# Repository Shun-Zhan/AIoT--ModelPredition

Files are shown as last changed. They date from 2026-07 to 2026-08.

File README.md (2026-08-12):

# ESP32-S3 智能灌溉

这是一个离线优先的智能灌溉系统。**ESP32-S3 是唯一的生产业务节点**：采集、五分钟历史、N-BEATS/SoilLSTM 推理、灌溉安全规则、水阀执行和可选云端大模型都在设备上完成。电脑或手机网页只是显示数据和转发用户操作；它们断开、关机或无互联网时，ESP32 的采集、预测和本地自动灌溉仍可继续运行。

官方赛题：[2026 乐鑫科技赛道 PDF](https://iot.sjtu.edu.cn/ueditor/net/upload/file/20260329/6391039317778793056390288.pdf)。

## 生产架构

```mermaid
flowchart LR
  S[传感器] --> E[ESP32-S3]
  E --> H[五分钟 V2 历史和 NTP 时间]
  H --> M[N-BEATS + SoilLSTM]
  M --> R[本地灌溉安全规则]
  R --> V[GPIO11 继电器和水阀]
  E <-->|Wi-Fi TCP 或 USB| D[电脑 Dashboard]
  D -->|UI 命令| E
  E <-->|可选 HTTPS| C[火山引擎云端大模型]
```

- ESP32 本地规则始终优先于云端建议。云端只能解释、问答和给出建议，不能绕过设备安全门或直接操作 GPIO11。
- 自动灌溉每次重启均关闭，需在 Dashboard 中人工启用；即使已启用，设备仍会校验 NTP 时间、完整传感器、288 点连续窗口、冷却时间、单次最长 60 秒和每日最长 600 秒。
- PC 端不运行生产预测、不做生产决策、不调用云端，也不保存或索取云端 API Key。训练和模型导出仍是开发工具，和日常 Dashboard 启动无关。

## 一键启动 Dashboard

仅需 Python 3.10+。首次启动会建立 `.venv` 并安装网页/串口接收依赖；**不检查云端 Key，也不读取 `artifacts/` 模型文件**。

### Windows

Wi-Fi 接收（推荐）：

```powershell
cd C:\Users\你的用户名\Desktop\AIoT--ModelPredition
.\start_dashboard.cmd -Wifi -Lan
```

USB 接收：

```powershell
.\start_dashboard.cmd -EspSerialPort COM3 -Lan
```

`-Lan` 让同一局域网中的手机访问 `http://电脑IPv4:8000/dashboard`。Windows 防火墙仅允许“专用网络”。停止后台进程：

```powershell
.\stop_dashboard.cmd
```

### macOS / Linux

Wi-Fi 接收（自动发现 ESP32）：

```bash
cd /你的路径/AIoT--ModelPredition
./start_dashboard.sh --wifi --lan
```

USB 接收：

```bash
./start_dashboard.sh --serial-port /dev/cu.wchusbserial10 --lan
```

若热点屏蔽 UDP 广播和 mDNS，可将串口打印的设备 IP 显式传入：

```bash
./start_dashboard.sh --wifi --esp-wifi-host 172.20.10.2 --lan
```

## Dashboard 的职责

Dashboard 从设备接收 `@TELEMETRY`、`@FORECAST`、`@IRRIGATION_STATE`、`@CLOUD_RESULT` 和 `@UI_ACK`，将最近状态缓存到 SQLite 后展示。网页按钮只写入待转发的 `@UI_COMMAND`；ESP32 收到后必须再次审核，再返回 ACK。

```text
网页按钮 -> 电脑转发 @UI_COMMAND -> ESP32 安全审核 -> @UI_ACK / @IRRIGATION_STATE -> Dashboard
```

因此“打开水阀”按钮只是请求，不能保证已经打开。以设备返回的 `@UI_ACK` 和 `@IRRIGATION_STATE` 中的阀门状态为准；`STOP_WATERING` 是任何状态下都允许的保守操作。

电脑断开后重新连接，Dashboard 只请求设备当前状态与后续遥测，不会把 PC 上陈旧的预测或决策下发给设备。

## ESP32 离线采集与预测

设备上电默认是 `OFFLINE_LOGGING`，每 **5 分钟**保存一个完整样本。任一必需传感器失败时，该 slot 不写入；设备每 15 秒重试，跨过 slot 仍失败则形成缺口，连续预测窗口从下一条完整样本重新累计。

- 连续 288 个五分钟样本为 24 小时窗口。满足后 ESP32 运行 float32 N-BEATS 和两层 SoilLSTM，输出下一小时 ET₀ 与 12 个五分钟土壤湿度预测点。
- 本方案不使用硬件 RTC。设备每次上电必须先成功连接互联网并完成 NTP 校时；Wi-Fi 连通后约 5 秒开始校时重试。当前运行周期内可继续离线采集、预测和自动灌溉，但断网重启后会回到 `clock_unset`，直到下一次 NTP 校时。
- `warming_up`、`clock_unset` 或模型错误时，可显示轻量 `edge_prediction` 风险提示；它不能直接开阀。
- 记录采用 V2（二进制版本、长度、连续序号、UTC epoch、slot、传感器有效标志和 CRC）。启动会恢复最新连续 288 条 V2 数据；不会要求再次等待 24 小时。

### 升级旧日志

V1 离线记录与 V2 不兼容。升级前先通过 USB 导出旧记录：

```bash
dual-forecast offline-log --action export
```

确认 CSV 已保存并检查后，再使用交互式二次确认或显式 `erase` 清除旧 V1 文件。固件不会静默删除或伪造迁移旧记录。

### 从导出 CSV 回灌预测历史

同一份由 `offline-log --action export` 导出的 CSV 可以通过 USB 回灌到 ESP32，作为模型的初始历史；无需切换到另一份演示固件。回灌只替换 ESP32 的 **V2 预测历史窗口**，不会删除普通离线导出日志、Wi-Fi 配置或云端配置；开始时会强制关阀并关闭自动灌溉。

先停止占用 USB 串口的 Dashboard/Arduino 串口监视器，再执行：

```bash
./stop_dashboard.sh
.venv/bin/python -m dual_forecast.cli offline-log \
  --serial-port /dev/cu.wchusbserial10 \
  --action import \
  --input "/完整路径/esp32-offline-log.csv"
```

Windows PowerShell：

```powershell
.\stop_dashboard.cmd
.\.venv\Scripts\python.exe -m dual_forecast.cli offline-log `
  --serial-port COM3 `
  --action import `
  --input "C:\完整路径\esp32-offline-log.csv"
```

电脑会校验原始导出列、传感器有效标志和五分钟连续性，并选取 CSV 中最长的一段连续完整记录，最多 288 条。旧 CSV 没有 UTC 时间列，ESP32 会按导入完成时刻向前连续排列这些历史点，再继续追加之后的真实五分钟采样。

- 导入 288 条：ESP32 立即排队运行模型，Dashboard 收到 `@FORECAST` 后自动画出一小时趋势图。
- 导入少于 288 条：Dashboard 显示 `N/288`，设备继续采集到 288 条后自动推理。例如导入 94 条，还需 194 条完整真实样本。
- CSV 中跨重启、缺采样或传感器失败的段不会拼接，避免把不连续时间序列误用于模型。

## 云端大模型

云端是可选增强，设备在有互联网时通过 HTTPS 直接访问火山引擎 OpenAI 兼容网关。API Key、是否启用、模型名和农田档案均由 ESP32 配网页面保存到设备 NVS：

- Key 不回显、不写入串口日志、遥测、SQLite 或 Git。
- 配网页面只显示“已配置”；提交空 Key 时保留现有 Key，清除需要显式操作。
- 网络、TLS、JSON 或网关失败只产生设备状态，**不影响**本地采集、预测和安全控制。
- 曾经暴露在终端、聊天记录或截图中的 Key 必须在正式部署前作废并重新生成。

电脑侧 `.env` 不再是云端配置位置。电脑没有网络时仍能显示设备数据；ESP32 所在局域网若没有互联网，则设备照常离线运行，云端请求显示为不可用即可。

## 硬件接线

| 功能 | ESP32-S3 引脚 | 接线/说明 |
| --- | --- | --- |
| 风速（当前使用） | GPIO6 ADC | OUT；若模块输出 0–5 V，必须分压到 0–3.3 V |
| 风速预留 | GPIO9 | 当前不接、不采样 |
| AHT20 | GPIO5 / GPIO8 | SDA / SCL，3.3 V，I²C 地址 0x38 |
| HW-611 BMP280 | GPIO3 / GPIO4 | SDA / SCL，3.3 V；CSB→3.3 V；SDO→GND 通常为 0x76 |
| ZH-SOIL7 土壤 | GPIO18 / GPIO17 | 设备 TTL UART 的 RX / TX，4800 8N1，Modbus-RTU 地址 0x03 |
| SN-300AL 太阳辐射 | GPIO16 / GPIO15 | 经自动收发 RS485 转换器的 RO / DI；4800 8N1，地址 0x01/0x02 |
| 水阀继电器 | GPIO11 | IN，3.3 V 单路继电器，高电平有效；上电默认 LOW |
| Feather I²C 电源控制 | GPIO7 | 不外接，禁止复用 |

土壤传感器这一版是 **TTL UART 电气层**，不是 RS485 电气层：模块的 TX 接 ESP32 GPIO18（RX），模块的 RX 接 ESP32 GPIO17（TX），并与 ESP32 共地。它传输的帧格式仍可以是 Modbus-RTU；“Modbus-RTU”是通信协议，不能据此判断必须使用 RS485。

太阳辐射总线才使用 RS485：两个探头 A 对 A、B 对 B 并联，接到独立的自动收发 RS485 转换器；转换器 RO→GPIO16，DI→GPIO15。太阳 1（0x01）是反射短波，太阳 2（0x02）是入射短波，净短波为 `max(入射 - 反射, 0)`。

本方案没有硬件 RTC。设备仅在 NTP 校时成功后将 ESP32 系统时钟视为可信时间；当前运行周期内即使暂时断网仍可继续采集、预测和自动灌溉，但断网重启后必须再次联网校时。

水阀的低压侧：继电器 DC+/VCC 接模块要求的 3.3 V，DC-/GND 与 ESP32 共地，IN 接 GPIO11。24 V 常闭水阀的触点侧：24 V 正极→COM，NO→水阀正极，水阀负极→24 V 负极。确认继电器触点的直流额定值高于负载；24 V 不能进入 ESP32 GPIO 或继电器 IN。

## ESP32 配网

无已保存网络、首次烧录或收到 `@WIFI_RESET` 时，ESP32 建立 `AIOT-SETUP-xxxxxx` 热点，密码为 `12345678`，在 `http://192.168.4.1/` 配置 2.4 GHz WPA2 网络。网络凭据和云端配置仅保存在 ESP32 NVS。普通手机热点、Windows 移动热点和家用路由器可用；5 GHz、网页认证/验证码和多数 802.1X 校园网需要专门适配。

## 开发：训练与模型导出

训练只在开发电脑进行；生产 Dashboard 启动不需要 `artifacts/`。模型更新后执行导出，再重新烧录 ESP32：

```bash
.venv/bin/python scripts/export_esp32_models.py
.venv/bin/python scripts/export_esp32_models.py --check
```

导出生成 `firmware/esp32_s3_all_sensors/generated/model_data.h`，其中包含 float32 权重、标准化器、模型版本和 SHA-256。不要手改该文件。

### Arduino 依赖与编译

Arduino IDE / `arduino-cli` 需安装 **ArduinoJson 7.4.2**。板型选择 `Adafruit Feather ESP32-S3 No PSRAM`，分区选择 `Default (3MB APP/1.5MB SPIFFS)`：

```bash
arduino-cli compile \
  --fqbn 'esp32:esp32:adafruit_feather_esp32s3_nopsram:PartitionScheme=default_8MB,CDCOnBoot=default,UploadMode=default' \
  --build-path /tmp/aiot-esp32-build \
  firmware/esp32_s3_all_sensors
```

详细固件协议与离线日志操作见 [firmware/esp32_s3_all_sensors/README.md](firmware/esp32_s3_all_sensors/README.md)。

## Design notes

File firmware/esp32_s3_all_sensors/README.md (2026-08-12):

# ESP32-S3 固件

该目录的固件是生产业务权威：它在 ESP32-S3 本机完成传感器采集、NTP 校时、离线 V2 历史、float32 N-BEATS/SoilLSTM 推理、灌溉安全审核、水阀控制，以及可选火山引擎云端大模型调用。电脑端仅接收和显示设备消息，并转发网页请求；电脑不参与生产预测、决策或云端调用。

## IDE 与依赖

使用 Arduino IDE 打开 `esp32_s3_all_sensors.ino`。板型选择 **Adafruit Feather ESP32-S3 No PSRAM**，Tools → Partition Scheme 选择 **Default (3MB APP/1.5MB SPIFFS)**。不要选 TinyUF2 FATFS 分区，否则 LittleFS 无法挂载。

通过 CH340 `/dev/cu.wchusbserial*` 或 Windows `COM*` 烧录时，设置 USB CDC On Boot → Disabled、Upload Mode → UART0 / Hardware CDC。

除 ESP32 Arduino Core 外，还需安装 **ArduinoJson 7.4.2**。模型权重由仓库根目录的 `scripts/export_esp32_models.py` 生成 `generated/model_data.h`，更新模型后必须重新烧录；不要手动修改生成文件。

```bash
.venv/bin/python scripts/export_esp32_models.py --check
arduino-cli compile \
  --fqbn 'esp32:esp32:adafruit_feather_esp32s3_nopsram:PartitionScheme=default_8MB,CDCOnBoot=default,UploadMode=default' \
  --build-path /tmp/aiot-esp32-build \
  firmware/esp32_s3_all_sensors
```

## 引脚与接线

| 功能 | ESP32-S3 | 外设侧 | 说明 |
| --- | --- | --- | --- |
| 风速（启用） | GPIO6 | OUT | ADC；0–5 V 信号先分压至 0–3.3 V |
| 风速预留 | GPIO9 | 不接 | 当前不采样 |
| AHT20 | GPIO5 / GPIO8 | SDA / SCL | 3.3 V，地址 0x38 |
| BMP280 / HW-611 | GPIO3 / GPIO4 | SDA / SCL | 3.3 V；CSB→3.3 V；SDO→GND 常为 0x76 |
| ZH-SOIL7 土壤 | GPIO18 / GPIO17 | TX / RX | TTL UART，4800 8N1，Modbus-RTU 地址 0x03 |
| SN-300AL 太阳辐射 | GPIO16 / GPIO15 | RS485 转换器 RO / DI | 4800 8N1，地址 0x01/0x02 |
| 水阀继电器 | GPIO11 | IN | 3.3 V、高电平有效；上电先置 LOW |
| Feather I²C 电源控制 | GPIO7 | 不外接 | 固件自动拉高，禁止复用 |

所有模块必须共地。本方案没有硬件 RTC：设备每次启动后先连接有互联网的 Wi-Fi，通过 NTP 校准 ESP32 系统时钟；Wi-Fi 连通后约 5 秒开始校时重试。校时成功前预测状态为 `clock_unset`，自动灌溉不会开启。校时成功后，在本次运行周期内即使暂时断网，设备仍可继续采集、预测和自动灌溉；断网重启则需再次 NTP 校时。

**土壤不是 RS485 电气层。** 该版本的 ZH-SOIL7 使用 TTL UART：传感器 TX→GPIO18（ESP32 RX），传感器 RX→GPIO17（ESP32 TX），共地。它的帧协议仍为 Modbus-RTU；协议不等于电气层，因此不要额外串接 RS485 转换器。

太阳辐射才需要 RS485 转换器：两个太阳探头 A 对 A、B 对 B 并联在独立太阳总线上，转换器 RO→GPIO16，DI→GPIO15。地址 0x01 是反射短波，0x02 是入射短波；净短波为 `max(入射 - 反射, 0)`。

继电器控制侧：DC+/VCC→模块要求的 3.3 V，DC-/GND→ESP32 GND，IN→GPIO11。24 V 常闭水阀的触点侧：24 V 正极→COM，NO→水阀正极，水阀负极→24 V 负极。24 V 不得接入 GPIO 或 IN；触点额定直流电压/电流应高于水阀负载。

## 离线记录、预测与安全

上电默认是 `OFFLINE_LOGGING`，每 **5 分钟**尝试写入一个完整样本。任一必需传感器失败时，该样本不会写入；设备每 15 秒重试，跨越本 slot 后记录缺口，新的连续窗口从下一条完整样本开始。

- V2 记录包含版本、记录长度、序号、UTC epoch、五分钟 slot、有效传感器标志和 CRC。
- 从 LittleFS 的轮换文件恢复最新连续 288 条 V2 记录。288 条完整的五分钟样本等于 24 小时，可立即推理。
- V1 与 V2 不兼容。升级前先用 `dual-forecast offline-log --action export` 导出 CSV；确认文件可用后，才通过明确 `erase` 操作清除旧记录。固件不静默清空 V1。
- 导出 CSV 可通过 `dual-forecast offline-log --action import --input <csv>` 经 USB 回灌到 V2 预测历史。导入时设备强制关阀并关闭自动模式；电脑校验 CSV 的完整记录和五分钟连续性，选择最长连续段，最多 288 条。导入 288 条立即推理，少于 288 条则继续追加真实采样直到窗口满。
- 本方案不使用硬件 RTC。设备在 NTP 校时成功后可将系统时钟作为当前运行周期的可信时间源；断网重启后回到 `clock_unset`，直到再次 NTP 校时。时间无效、窗口未满、缺失数据或模型错误时，仅允许 `edge_prediction` 风险提示，禁止自动开阀。
- 自动模式只保存在 RAM，**每次重启默认关闭**。即使人工打开自动模式，也要满足完整传感器、预测就绪、冷却、单次 60 秒和每日 600 秒限额。
- 本地自动开阀不依赖电脑心跳；PC 发起的调试/人工开阀仍受传输心跳保护。任何状态都接受 STOP 并关阀。

## Wi-Fi、云端与配网

首次烧录、没有已保存网络或收到 `@WIFI_RESET` 时，设备会创建 `AIOT-SETUP-xxxxxx` 配置热点，密码 `12345678`，页面为 `http://192.168.4.1/`。支持 2.4 GHz WPA2 网络、手机热点和 Windows 移动热点；5 GHz、网页认证和 802.1X 校园网需额外适配。

配网页面保存 Wi-Fi 凭据，以及云端开关、模型名、农田档案和 API Key。云端 Key 只保存在 ESP32 NVS：页面只显示是否已配置，绝不回显、写日志、出现在遥测或提交到 Git。空 Key 更新保留旧 Key；清除是显式操作。

设备通过 HTTPS 直接调用火山引擎网关，并验证根证书；禁止使用 `setInsecure()`。云端网络/TLS/JSON/服务失败时只返回离线状态，采集、预测和本地安全闭环继续运行。正式部署前应作废历史聊天、终端或截图中泄露过的 Key。

## 与 Dashboard 的协议

设备上行：

```text
@TELEMETRY { ... }
@FORECAST { "schemaVersion":"2.0", ... }
@IRRIGATION_STATE { "schemaVersion":"2.0", ... }
@CLOUD_RESULT { "schemaVersion":"2.0", ... }
@UI_ACK { "schemaVersion":"2.0", ... }
```

电脑/网页下行：

```text
@UI_COMMAND { "action":"SET_AUTO_MODE" | "CONFIRM_WATERING" | "CANCEL" | "STOP_WATERING" | "CLOUD_ANALYZE" | "CLOUD_CHAT", ... }
```

设备对所有开阀请求重新执行完整安全审核。Dashboard 的按钮表示“已请求”，不是“已执行”；以 `@UI_ACK` 和 `@IRRIGATION_STATE` 中的设备状态为准。

Wi-Fi 模式下设备以 UDP 3334 广播、TCP 3333 提供遥测端点；电脑可自动发现。USB 波特率为 115200，Arduino 串口监视器不能与电脑接收器同时占用该端口。

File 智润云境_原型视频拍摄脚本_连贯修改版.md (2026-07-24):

# 《智润云境》作品原型视频拍摄脚本（连贯修改版）

## 一、成片定位

- 建议时长：6 分 30 秒左右（可接受范围 6–7 分钟）
- 叙事主线：校园灌溉痛点 → 系统组成 → 实时感知 → 本地预测 → 云端分析 → 灌溉执行 → 创新总结
- 核心记忆点：系统不是“湿度低就浇水”，而是综合环境数据预测需水趋势，再给出有依据的灌溉建议
- 推荐形式：1 名主讲人出镜，另 1 名队员操作；以实物演示和录屏为主，架构图只做辅助
- 开场原则：前 20 秒出现作品实物或阀门出水画面，前 1 分钟说清作品解决什么问题

## 二、拍摄前准备

### 必拍实物

1. ESP32-S3 主控板近景，芯片或模组型号清晰可见。
2. AHT20、BMP280/BME280、RS485 土壤温湿度、双路太阳辐射和当前启用的单路风速传感器。
3. 电脑端边缘网关、GPIO11 继电器、24 V 常闭水阀、管路和盆栽或模拟绿地。
4. 电脑上的实时 Dashboard、预测模型状态、云端分析结果和执行日志。
5. 火山引擎大模型的真实问答或分析摘要。

### 建议提前准备的演示状态

- 实时数据可以稳定刷新，传感器均正常在线。
- 准备一盆偏干土壤，或加载一段标明“历史实测回放”的真实干燥数据。
- 电磁阀或水泵能够安全动作，出水效果清楚。
- 提前积累足够的连续数据，确保预测模型能够返回结果。
- 提前测试大模型问答，避免现场因网络或接口波动影响拍摄。

> 如果现场无法稳定复现某个状态，可以使用提前录制的真实测试片段，并在画面上标注“历史实测回放”。不要把模拟数据包装成现场实测数据。

## 三、详细分镜与口播

| 时间 | 画面与镜头 | 口播参考 | 屏幕字幕/后期提示 |
|---|---|---|---|
| 00:00–00:12 | 干燥土壤特写 → Dashboard 出现缺水风险 → 阀门开启出水 → 作品全景。 | “如果校园绿化不再只按固定时间浇水，而是能提前判断植物接下来是否缺水，会发生什么？” | 大字标题：`智润云境`；副标题：`边缘 AIoT 智慧灌溉决策系统` |
| 00:12–00:35 | 主讲人站在原型旁，中景；穿插校园草坪或盆栽画面。 | “大家好，我们的作品是‘智润云境’。针对校园绿化依赖人工经验、定时灌溉容易造成用水不合理的问题，我们设计了一套集环境感知、本地预测、智能分析和灌溉控制于一体的系统。” | 关键词：`多源感知`、`趋势预测`、`按需灌溉` |
| 00:35–00:58 | 左侧展示传统阈值判断，右侧展示系统流程简图。 | “普通灌溉系统往往只看土壤湿度：低于阈值就浇水。但植物的需水状态还会受到气温、空气湿度、太阳辐射和风速影响。我们的系统把这些数据放在一起分析，预测未来一小时的蒸散和土壤湿度变化。” | 对比字幕：`单一湿度阈值` → `多源数据 + 趋势预测` |
| 00:58–01:22 | 推近 ESP32-S3，依次扫过各传感器，并标注名称。 | “系统以乐鑫 ESP32-S3 为核心主控，采集空气温湿度、大气压力、土壤温湿度、风速和两路太阳辐射。Solar 2 测量入射短波，Solar 1 测量反射短波，两者相减得到净短波辐射，为 ET₀，也就是参考作物蒸散量的计算和预测提供输入。” | `指定主控：ESP32-S3`；`Rs↓−Rs↑＝净短波辐射` |
| 01:22–01:50 | 展示 Wi-Fi TCP 数据流、USB 连接和电脑端 Dashboard，录到实时数据刷新。 | “ESP32-S3 通过同一 2.4 GHz 局域网，把采集数据经 TCP 发送到电脑，USB 作为备用连接。电脑上的 FastAPI 负责接收数据并把功能提供给网页，SQLite 则像一本保存在本机的电子台账，记录传感器数据、预测结果和操作日志。神经网络也在这台电脑上运行，ESP32 主要负责采集和执行。” | 简图：`传感器 → ESP32-S3 → Wi-Fi TCP / USB → 电脑端`；角标：`FastAPI：本地服务`、`SQLite：本地数据存储` |
| 01:50–02:05 | 作品全景俯拍，再切到土壤探头插入偏干土壤。 | “下面以一组偏干土壤数据为例，看看系统怎样从实时感知走到灌溉建议。” | 章节条：`原型演示：从感知到执行` |
| 02:05–02:32 | Dashboard 录屏，传感器卡片持续刷新；画中画保留实物。 | “ESP32-S3 持续采集环境数据，页面同步显示空气、土壤、风速和辐射信息。当前土壤湿度正在下降，同时光照较强，系统会把这些数据整理成连续的时间序列，交给电脑端模型分析。” | 高亮真实读数；角标：`① 多源数据实时感知` |
| 02:32–03:02 | 展示 Dashboard 的未来一小时双曲线，先带到模型状态和样本数，再依次放大 ET₀ 与土壤湿度预测。 | “电脑端以连续二百八十八个五分钟数据点，也就是约二十四小时的数据为输入。N-BEATS 预测未来一小时的 ET₀，LSTM 预测未来十二个五分钟时段的土壤湿度。两条曲线分别使用独立纵轴，可以直观看到蒸散需求和土壤湿度的变化趋势。快速测试模式只用来确认数据链路和模型流程能否跑通，不能作为精度证明。” | `288 个点 ≈ 24 小时`；`预测未来 12 步 ≈ 1 小时`；`快速测试模式只验证链路` |
| 03:02–03:32 | 点击“请求一次分析”，展示火山引擎真实调用结果和结构化建议。 | “有了实时数据和本地预测后，系统可以请求云端大模型进行综合分析。上传的内容包括当前环境、近期趋势、预测结果和设备状态。大模型返回分析依据和结构化建议，帮助运维人员快速理解这片区域当前为什么可能需要灌溉。” | 角标：`② 本地预测 + 云端分析`；高亮数据时间范围和建议内容 |
| 03:32–04:00 | 现场文字或语音提问：“最近是否存在高蒸散风险？”展示回答和依据。 | “运维人员也可以直接提问，比如‘最近是否存在高蒸散风险’。系统会结合已经采集到的数据回答，并标出判断依据。语音输入和朗读由浏览器提供，不支持时仍可正常使用文字问答。” | 角标：`自然语言问答`；显示：`回答依据来自系统数据` |
| 04:00–04:32 | 操作者在 Dashboard 确认灌溉；切到 GPIO11 继电器、水阀出水和页面状态更新，保留 2 秒水流声。 | “当系统给出灌溉建议后，由操作人员在页面确认。电脑把控制指令发送给 ESP32-S3，主控驱动 GPIO11 继电器打开水阀。设备返回执行结果后，页面同步更新状态，完成从感知、预测到实际灌溉的闭环。” | 流程逐项点亮：`感知 → 预测 → 建议 → 确认 → 执行` |
| 04:32–04:52 | 展示灌溉后的土壤湿度变化和操作日志。 | “灌溉过程中，系统继续采集土壤数据，并记录建议时间、执行时长和设备反馈。这些历史记录可以用于复盘，也能为后续模型优化提供数据。” | 角标：`③ 过程可记录、结果可追溯` |
| 04:52–05:28 | 简洁架构图全屏，随后快速切换净短波、预测结果、云端问答和手机 Dashboard。 | “整套系统分为三层：ESP32-S3 完成现场感知和设备执行；电脑端保存数据、运行预测模型并提供可视化页面；云端大模型负责结合上下文生成分析建议。三部分通过清晰的数据接口配合，既能展示完整的 AIoT 链路，也方便后续扩展。” | 三层架构：`设备端`、`电脑端边缘网关`、`云端大模型` |
| 05:28–06:02 | 依次展示双太阳辐射、模型预测、手机访问页面和实物运行画面。 | “项目有三个主要特点。第一，分别测量入射和反射太阳辐射，用净短波数据支撑 ET₀ 分析；第二，在电脑端同时使用 N-BEATS 和 LSTM，分别预测蒸散与土壤湿度趋势；第三，电脑和手机都能在局域网内查看实时状态，方便现场巡检。” | 大字：`净短波感知`、`双模型预测`、`局域网巡检` |
| 06:02–06:25 | 展示主控、传感器、RS485 转换器、继电器、24 V 常闭水阀和电脑页面。 | “从传感器采集、局域网传输，到本地预测、云端分析和水阀执行，我们已经完成了可运行的原型闭环。后续还会继续积累真实土壤数据，对模型进行校准和评估。” | 字幕：`真实原型闭环`；`持续积累实测数据` |
| 06:25–06:42 | 团队成员与作品同框，最后切作品 Logo。 | “智润云境，让灌溉从按时执行，走向按需决策。以上是我们的作品介绍，感谢各位评委老师。” | 收尾：作品名、团队名；不要出现 Wi-Fi 密码、API Key 或个人联系方式 |

## 四、可直接使用的 30 秒开场词

“如果校园绿化不再只按固定时间浇水，而是能结合土壤状态和蒸散趋势，提前判断植物接下来是否缺水，会发生什么？大家好，我们的作品是‘智润云境’，一套基于 ESP32-S3、电脑端预测模型和云端大模型的智慧灌溉系统。它采集空气、土壤、风速和太阳辐射数据，通过 N-BEATS 和 LSTM 预测未来趋势，再把分析结果转化为清楚、可追溯的灌溉建议。接下来，我们用真实原型演示这条完整链路。”

## 五、关于预测画面的拍摄说明

当前 Dashboard 已经能够显示：

- 模型当前状态；
- 已积累的连续样本数；
- 未来 12 个五分钟时段的 ET₀ 预测曲线；
- 未来 12 个五分钟时段的土壤湿度预测曲线；
- 未来一小时累计 ET₀，以及土壤湿度起止值摘要。

两张图使用独立纵轴，拍摄时可以先展示完整卡片，再分别放大曲线。模型未积累满 288 个连续数据点时，页面会显示预热提示，不会生成虚假的占位曲线。

## 六、拍摄与剪辑建议

### 镜头

- 统一使用横屏 16:9，建议拍摄和导出分辨率为 1920×1080。
- 人物口播使用固定机位，实物近景缓慢推拉，避免全程手持晃动。
- 页面内容优先录屏，再与实物画面做画中画组合。
- 每个关键实物至少准备全景、中景和接口或型号特写。
- 阀门出水是全片最直观的动作，可从继电器指示灯、阀门和出水口三个角度拍摄。

### 声音

- 在安静环境单独录制口播，手机或领夹麦距离嘴部约 15–20 cm。
- 背景音乐保持较低音量，阀门动作和水流声可以短暂保留。
- 专业名词配字幕即可，不要把整段口播全文堆在画面上。

### 节奏

- 开头 1 分钟每 3–5 秒切换一次镜头，尽快建立问题和作品印象。
- 原型演示段的每个页面停留 5–8 秒，让评委看清真实数据。
- 每个镜头只解释一个重点，复杂公式放在设计文档中。
- 转场以直切和简单淡入淡出为主，不让动画盖过实物。

## 七、赛题要求显性对照

| 赛题必备项 | 口播必须说到 | 对应证据画面 |
|---|---|---|
| 指定乐鑫主控 | “以乐鑫 ESP32-S3 为核心主控” | 模组型号清晰特写 |
| 传感器数据融合 | “综合空气、土壤、风速和太阳辐射数据” | 多传感器实物 + 实时数据卡片 |
| 对接云端大模型 | “通过火山引擎接口请求云端大模型分析” | 真实请求结果或问答界面 |
| 上下行交互 | “上传系统数据，返回分析建议” | 请求内容摘要 + 返回结果 |

可以自然带出的加分点包括净短波感知、N-BEATS/LSTM 双模型预测、自然语言交互、手机巡检和常闭水阀。节水可以作为项目目标，但在没有对照实验前不要展示具体节水百分比。

## 八、常见失分点

1. 不要把视频拍成 PPT 朗读，实物、录屏和真实动作应占主要时长。
2. 前 1 分钟必须出现作品和实际问题，不要先讲过长的项目背景。
3. 不要只说“使用了大模型”，要展示系统向它提供了什么数据、它返回了什么内容。
4. 不要口头宣称“七类传感器”。应以当前实际接线和固件启用情况为准。
5. 不要暴露 Wi-Fi 密码、服务器地址、API Key、学校内网信息或个人联系方式。
6. 不要使用没有记录支撑的精度、节水率或“已经部署”等表述。
7. 拍摄预测曲线时，应同时带到模型状态和样本数，避免把快速测试结果表述成精度验证。

## 九、导出检查

- 容器格式：MP4
- 视频编码：H.264
- 音频编码：AAC
- 分辨率：1920×1080 或更低
- 帧率：25 或 30 fps
- 建议码率：视频 2.5–3.5 Mbps，音频 AAC 128 kbps
- 按 6 分 40 秒、约 3 Mbps 导出，文件通常低于 160 MB
- 导出后完整播放一次，检查黑帧、爆音、字幕出界、数据遮挡和隐私信息

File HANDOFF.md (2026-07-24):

# AIoT 智能灌溉项目交接文档

> 项目目录：`/Users/jiahaoruan/Work/IOT/AIoT--ModelPredition`  
> 最近整理：2026-07-23  
> 交接目标：让下一位开发者能在不依赖聊天记录的前提下，继续完成、验证和提交本项目。

## 1. 当前项目做什么

这是一个 ESP32-S3 智能灌溉系统：ESP32-S3 采集环境数据，通过 Wi-Fi 或 USB 串口发送到电脑；电脑端保存数据、运行本地预测、提供实时 Dashboard、调用可选的火山引擎云端大模型，并在本地安全规则审核后控制 ESP32 GPIO11 上的继电器水阀。

系统采用“离线主干 + 云端增强”设计：局域网断开互联网时，采集、电脑网页、SQLite、本地预测、边缘风险分析、人工确认开关阀仍可使用；云端大模型分析和云端 AI 自动灌溉不可用，且不会因云端失败而开阀。

## 2. 重要目录

| 位置 | 作用 |
| --- | --- |
| `firmware/esp32_s3_all_sensors/esp32_s3_all_sensors.ino` | ESP32-S3 主固件：采集、Wi-Fi 配网/TCP、USB 协议、继电器、设备侧安全保护 |
| `firmware/esp32_s3_all_sensors/README.md` | 最准确的固件接线、烧录、Wi-Fi 和协议说明 |
| `dual_forecast/esp32_receiver.py` | Wi-Fi TCP / USB 串口接收器，接收 `@TELEMETRY`、转发命令并等待 ACK |
| `dual_forecast/service.py` | FastAPI 接口和内嵌 Dashboard 前端 |
| `dual_forecast/irrigation.py` | 云端建议、本地边缘风险、本地安全审核、命令入队 |
| `dual_forecast/cloud.py` | 火山引擎 OpenAI 兼容网关适配与结构化回答解析 |
| `dual_forecast/config.py` | `.env` 加载和运行配置 |
| `dual_forecast/storage.py` | SQLite 历史、预测、事件、决策、指令和 ACK |
| `start_dashboard.sh` / `scripts/start_dashboard.ps1` | macOS/Linux、Windows 一键启动 |
| `README.md` | 面向使用者的总说明、比赛对照、运行流程 |
| `tests/` | API、云端模拟、边缘风险和水阀安全逻辑测试 |

## 3. 已完成的功能

### ESP32-S3 与传感器

- 多传感器统一 `SensorSnapshot`，上报 `@TELEMETRY` JSON。
- AHT20 空气温湿度，BMP280/BME280 气压，双路风速，土壤 RS485，双路太阳辐射 RS485；Solar 1 为反射短波 Rs↑，Solar 2 为入射短波 Rs↓，ET₀ 使用净短波 Rns。
- AHT20 / DHT11 可选，当前推荐 AHT20；DHT11 是备用方案。
- 首次或执行 `@WIFI_RESET` 后开启配网热点；保存凭据到 ESP32 NVS，后续重启会自动重连。
- ESP32 成功入网后开启 TCP 3333，并每 3 秒 UDP 3334 广播发现消息；电脑用自动发现，无需固定 IP。
- USB 串口调试保留，波特率 115200。
- 设备侧包含命令 TTL、重复 requestId 去重、最长 60 秒开阀、8 秒无主机心跳提前关阀、上电默认关阀。
- ESP32 还会生成轻量、可解释的断网降级预测 `edge_prediction`；它只提示风险，不能直接开阀。

### 电脑端本地能力

- FastAPI Dashboard：实时传感器、历史、预测、边缘风险、事件、报告、云端分析和水阀状态。
- SQLite 保存实时样本、预测、环境事件、云端调用、灌溉决策、命令和设备 ACK。
- 本地 N-BEATS / LSTM 预测，并有 288 样本预热逻辑。
- 多源数据融合、数据新鲜度校验、传感器失败事件、干旱候选和高蒸散风险判断。
- 本地动态采样建议与独立 `@CONFIG`/`@CONFIG_ACK` 协议；不能误触发水阀命令。
- 节水、日报、事件时间线及本地风险说明。
- macOS/Linux 与 Windows 的一键启动；支持 USB 模式和 Wi-Fi 自动发现模式。

### 云端大模型与控制闭环

- 对接火山引擎 VEI 的 OpenAI 兼容 `/v1/chat/completions` 接口。
- 上行上下文包含当前有效数据、趋势、本地预测、异常、灌溉日志和可选农田资料；未配置天气数据时显式提示模型不得臆造天气或降雨。
- 要求模型返回结构化 `START_WATERING`、`STOP_WATERING` 或 `NO_OP` 建议，再由电脑端本地安全层复核。
- 默认需要网页长按确认，才会进入 ESP32 命令队列；网页、云端模型均不直接操作 GPIO。
- 已增加“显式开启的 AI 自动灌溉”安全闭环，默认关闭。自动开阀仍必须同时满足：完整且新鲜的 ESP32 数据、`IRRIGATION_CANDIDATE` 风险、本地预测就绪、AI 置信度阈值、土壤阈值、冷却时间、单次时长和每日上限。
- 云端不可达、模型输出不合法、数据缺失/陈旧、预测未就绪等任何一种情况都会保持 `NO_OP` 或保留建议，不会开阀。

## 4. 当前固件接线（交给硬件组）

| 功能 | ESP32-S3 引脚 | 对外模块接法 / 注意事项 |
| --- | --- | --- |
| 风速（当前启用） | GPIO6 | 接传感器 OUT；0–5 V 输出必须先分压至 0–3.3 V |
| GPIO9 | 不接 | 预留给未来第二路风速；当前固件不采样 |
| AHT20 | GPIO5 / GPIO8 | SDA / SCL；VCC→3.3 V，GND 共地，地址 0x38 |
| DHT11 备用 | GPIO10 | OUT；当前固件默认不使用 |
| BMP280/BME280（HW-611） | GPIO3 / GPIO4 | SDA / SCL；VCC→3.3 V，GND；CSB→3.3 V，SDO→GND 使用地址 0x76 |
| 土壤传感器 | GPIO18 / GPIO17 | 经独立、3.3 V UART 兼容的自动收发 RS485 转换器：转换器 RO→GPIO18，DI→GPIO17；地址 0x03，4800 8N1 |
| Solar 1（反射 Rs↑）+ Solar 2（入射 Rs↓） | GPIO16 / GPIO15 | 经另一独立 RS485 转换器：RO→GPIO16，DI→GPIO15；两个探头 A/B 可并联，地址依次为 0x01、0x02，4800 8N1；计算净短波 `max(Solar2 - Solar1, 0)` |
| 水阀继电器输入 | GPIO11 | 3.3 V 一路继电器，当前配置为高电平有效；模块 GND 必须和 ESP32 共地 |
| 板载 I2C 电源控制 | GPIO7 | 程序使用，禁止外接或复用 |

24 V 常闭水阀的负载侧：`24V+ → COM`，`NO → 水阀正极`，`水阀负极 → 24V-`。继电器低压控制侧和 24 V 负载侧电气隔离，但触点额定直流电压/电流必须覆盖水阀负载。24 V 绝不能接入 ESP32 GPIO。

## 5. 日常运行流程

### ESP32 一次性配网

1. 烧录主固件并打开 USB 串口监视器（115200）。
2. 首次烧录、没有已保存网络、或串口发送 `@WIFI_RESET` 时，手机连接临时配网热点。
3. 打开固件串口输出中提示的配网页面，输入当前 2.4 GHz Wi-Fi/手机热点名称和密码。
4. 看到 `Connected. SSID=... IP=...` 后，凭据已经存入 NVS；普通 reset 和断电重启不需要再次配置。

### macOS/Linux Dashboard

在项目根目录运行：

```bash
./start_dashboard.sh --wifi --lan
```

`--wifi` 使用 UDP 3334 自动发现 ESP32，再连 TCP 3333；`--lan` 让手机可以访问电脑网页。电脑浏览器访问 `http://127.0.0.1:8000/dashboard`。手机和电脑在同一局域网时，访问页面显示的电脑局域网地址或二维码。

### Windows Dashboard

在 PowerShell 中进入项目根目录运行：

```powershell
.\start_dashboard.cmd --wifi --lan
```

首次运行会创建 `.venv` 并安装依赖。不要在 PowerShell 中使用 macOS/Linux 的 `source .venv/bin/activate`；如果需要手动激活，命令是：

```powershell
.\.venv\Scripts\Activate.ps1
```

### USB 降级模式

Wi-Fi 不可用时，保留 USB 数据线，关闭 Arduino Serial Monitor 后运行：

```bash
./start_dashboard.sh --serial-port /dev/cu.wchusbserial10 --lan
```

Windows 则替换为实际 COM 口，例如：

```powershell
.\start_dashboard.cmd --serial-port COM5 --lan
```

## 6. 云端配置与当前网络状态解释

真实 Key 只应放入项目根目录、已被 Git 忽略的 `.env`，不得写进 README、源码、测试、提交记录或交接文档。参考 `.env.example`：

```dotenv
AIOT_LLM_ENABLED=1
VEI_API_KEY=你的火山引擎密钥
VEI_BASE_URL=https://ai-gateway.vei.volces.com/v1
VEI_MODEL=doubao-1.5-thinking-pro
AIOT_AUTO_IRRIGATION_ENABLED=0
```

启动脚本会在 Key 缺失/被拒绝时提示输入并保存到 `.env`。当前实现中：

- “云端：已启用”表示本机已配置并打开云端功能开关，不等价于此刻互联网可达。
- 启动输出 `Cloud gateway is temporarily unreachable`、`URLError` 或页面 `gateway_error` 表示当前无法访问火山引擎。
- 无互联网但 ESP32、电脑、手机位于同一局域网时，Wi-Fi telemetry 和 Dashboard 仍然正常，这是设计目标。
- 云端不可达时不能获得新的云端 AI 判断，也不能走云端 AI 自动开阀；本地人工确认与设备侧安全保护仍可工作。

## 7. 当前 Git 状态（必须注意）

仓库最近已提交的基础提交包括：

```text
2aebac9 忽略本地编译产物与临时固件
cedf795 完善 Wi-Fi 自动接收与跨平台一键启动
a865cc5 统一 Wi-Fi 配网热点密码
568a9ce 增加 ESP32 手机 Wi-Fi 配网
e838098 完善边缘事件与移动巡检能力
1953788 实现云端大模型增强与安全灌溉闭环
```

但当前工作区有一批**尚未提交**的增强：`.env` 自动加载、启动时云端 Key 引导、农田资料注入、云端响应校验、显式 AI 自动灌溉安全门、Dashboard 云端/水阀信息优化，以及对应测试。涉及的修改文件为：

```text
.env.example
README.md
dual_forecast/cli.py
dual_forecast/cloud.py
dual_forecast/config.py
dual_forecast/irrigation.py
dual_forecast/schemas.py
dual_forecast/service.py
scripts/start_dashboard.ps1
scripts/start_dashboard.sh
tests/test_cloud.py
tests/test_edge_and_reports.py
tests/test_irrigation.py
tests/test_service.py
```

已有验证结果：

```text
.venv/bin/python -m pytest -q
58 passed, 2 skipped

git diff --check
通过
```

接手者在理解并复核后，应将这批修改作为单独提交提交；不要把 `.env`、`runtime/`、虚拟环境、SQLite、日志、Arduino 缓存或真实 API Key 加入 Git。

## 8. 推荐的下一步工作

### P0：完成当前未提交改动的验收与提交

- 运行完整测试与 `git diff --check`，核对 Dashboard 及 API 没有破坏已有 USB/Wi-Fi 链路。
- 用真实联网环境执行一次 `cloud-check` 和一次真实云端分析，记录成功响应、模型、延迟和结构化建议，作为比赛验收证据。
- 提交当前改动，提交信息建议：`完善云端大模型配置与自动灌溉安全闭环`。

### P1：修正 Dashboard 云端状态文案

当前页面“云端：已启用”容易被理解为“已经联网”。建议在 `/v1/cloud/status` 和 Dashboard 中拆分为：

- `未配置`：没有 Key 或 `AIOT_LLM_ENABLED=0`。
- `已配置，当前不可达`：保存了 Key，但最近检查/调用是 `URLError`、超时或 HTTP 失败；显示“离线主干运行”。
- `已连接`：最近一次真实调用成功；显示最近成功时间、模型、耗时。

状态检测应使用最近调用结果或短时间缓存，不要让 Dashboard 每次轮询都发真实云端请求。

### P1：现场端到端验收

- ESP32 在真实 2.4 GHz 热点下重新上电，确认自动入网、UDP 发现、TCP telemetry、Dashboard “实时数据新鲜”。
- 断互联网但保留局域网，确认本地 Dashboard、预测、SQLite 和人工开关阀仍可用；确认云端分析安全地显示不可达而不开阀。
- 恢复互联网，确认云端分析有真实成功记录；不要把 API Key 或含 Key 的日志截图公开。
- 先断开 24 V 水阀，仅观察继电器 LED、`@COMMAND`、`@ACK`、网页状态；再接真实水阀验证 NO/COM 线路。
- 校准风速 ADC 分压和换算系数；当前 0.0 风速、0.0 土壤湿度、0 W/m² 可能是实际传感器/接线值，不应在软件中伪造有效数据。

### P2：可选功能扩展（需明确授权后再做）

- 如需在无互联网时也自动灌溉，应单独实现并默认关闭 `AIOT_OFFLINE_IRRIGATION_ENABLED`：只能由本地预测 + 阈值规则 + 相同安全门触发，绝不能把它伪装成云端 AI 决策。
- 如要增加天气预报、作物知识或地区信息，必须接入可信数据源，并在云端提示中标注其采集时间与缺失状态。
- 如要再加显示屏，重新选定并验证模块协议/供电/电平转换后再做；此前 M 系列串口屏试验已停止，当前 GPIO11 专用于水阀，不应复用。
- 如要加入语音/手机交互，仅能作为“请求分析/人工确认”的输入方式，不能绕过后端安全审核直接控制继电器。

## 9. 常用排查命令

```bash
# 查看当前改动与最近提交
git status --short
git log --oneline -8

# Python 测试
.venv/bin/python -m pytest -q

# macOS/Linux 观察接收器日志；持续等待新输出是正常现象，Ctrl+C 退出
tail -f runtime/logs/esp32-receiver.out.log

# 健康检查与最新 Dashboard 数据
curl http://127.0.0.1:8000/health
curl http://127.0.0.1:8000/v1/dashboard/latest
curl http://127.0.0.1:8000/v1/cloud/status
```

Windows PowerShell：

```powershell
Get-Content .\runtime\logs\esp32-receiver.out.log -Tail 40 -Wait
Invoke-WebRequest http://127.0.0.1:8000/health
```

## 10. 安全与演示底线

- 任何 API Key、Wi-Fi 密码、数据库和运行日志都不提交 Git。
- 云端模型只能建议，不能直接开阀；电脑本地安全层和 ESP32 双重校验不可绕过。
- 自动灌溉必须显式打开，默认关闭；首次验收先断开真实水阀负载。
- 任何云端错误、传感器缺失、数据陈旧、预测预热不足或通信 ACK 超时，都应进入保守状态而不是继续开阀。
- 比赛演示应准备联网、仅局域网、USB 三种链路的演示说明，清楚表述各自能做和不能做的事情。

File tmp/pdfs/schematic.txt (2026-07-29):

         1                                                                2                                                         3                                                                 4                             5                                                      6

    直流可调输出                                                                                                                          直流稳压输出                                                                                   OLED显示
                                                                                                            VO
                                                                                                                                                                                                                                   GND
                                                                                                                                    VIN                                     U3
                                 VIN                                                                                                                                                                                                                          H2
                                                                                  U5                                                                             1
                                       VIN                                                                                                                                  15.5*10.5*21                                                                  1
A              C6                                  D4                 1                                                                                       1                                                                                             1                                       A
                                                                                  15.5*10.5*21                    R4                                                               5V
                                                                                                                                                                                                                             +5V
                                                                                                                                                                                                                                                          2
                                                                    1                                                                                                                                                                                       2
                                                                                                                  2K                                                                                                                SCL                   3
                                                                                                                                                      U2                                +5V                                                                 3
                                                                                                                                                                                                                                    SDA                   4
               330nF                              1N4001                                                                                      C2 1                           3                                                                              4
                                                                                                                                                       VIN        VOUT
                                                                                                                                              330nF
    U4                                                                               VO                                                                                                                                                                  H4
                                                                                                                                                             GND                              C3
                    3                                                                                                  LED2                                                                                                         SCL                 1
              INPUT                                                                                                                                          2                                100nF                                                       1
                    2                                                                                                                                 GND                                                                           SDA                 2
             OUTPUT                                                                                                                                                                                                                                       2
                    1
             ADJUST                                                                        VO
                                                                              R3                                                                      LM7805CT
                                                             D3
    LM317T                                                                    240Ω
                                                           1N4001                                                                                                    LED1
                                        ADJ

                                                                                                 C5                                              R1
                                                                                                 1uF        VO                          +5V
                                                                                                                  H3
                                                                                                                                                 2K
                                                                                                                 1
                                                 R2                            C4                                  1
                                                                                                                 2
                                                 5kΩ                           10uF                                2

                                                                                                            VO
                                                        GND1                                                      H8
B                                                                                                                1                                                                                                                                                                                  B
                                                                                                                   1
                                                                                                                 2
                                                                                                                   2
                                                                                                                                                                                                                                                                       C20        C19
                                                                                                                                                                                                                                                                       10uF       100nF
                                                                                                                                                                                                                                                                                          3V3
                                                                                                                                                  H5
                                                                                                                                                                                                                            C18          C17
                                                                                                                                                 1                                                                          10uF         100nF
                                                                                                                                                   1
                                                                                                                                                 2                                                               +5V
                                                                                                                                                   2
                                                                                                                                                 3
                                                                                                                                                   3
                                                                                                                                                 4
                                                                                                                                                   4
                                                                                                                                                                                                                                                 3
                                                                                                                                                                                                                                             VIN          U7
                                                                                                                                                                                                                                                 2
                                                                                                                                                                                                                                           VOUT

    变压整流电路
                                                                                                                                                                                                                                                 1
                                                                                                                                GND                                                                                                         GND
                                                                                                                              3V3                 H6
                                                                              整流后                                                                1
                                                                                                                                                   1
                                                                                                                                                                                                                                                 VOUT
                                                        变压后                                VIN                                                   2
                                                                                                                                                   2
                                                                                                                                                 3
                                                                                                                                                   3
                                                                                                                                                 4                                                                                           4
                            U1                                                                                                                     4
                        1                    3

     H1                                                                                                C1
C                2                                                                                                            +5V                 H7                                                                                                                                                C
               2                       OUT
                                                                                                   2200uF
                 1          IN
                                                               D1                                                                                1
               1                                                                                                                                   1
                                                               1              4                                                                  2
                                                                 +        AC                                                                       2
                                                               2              3                                                                  3
                        2                    4                   AC         -                                                                      3
                                                                                                                                                 4
                                                                                                                                                   4
                                                               2W10

                                                                                                                                                                                                                                    詹顺-23122637
                                                                                                                                                                                                                                           更新日期                        2026-07-21
                                                                                                                              原理图                                                                 Schematic1                               创建日期                        2025-12-29
                     SCREW1                        SCREW2
                                                                                                                              图页                                                                            P1                             物料编码
                                                                                                                              绘制

D                    SCREW3                        SCREW4
                                                                                                                              审阅                                                                                               生产实习zs                                                               D

                                                                                                                                                                                                          版本           尺寸                        页                 1          共                 1

                                                                                                                                                                                                          V1.0         A4                                     嘉立创EDA
         1                                                                2                                                         3                                                                 4                             5                                                      6

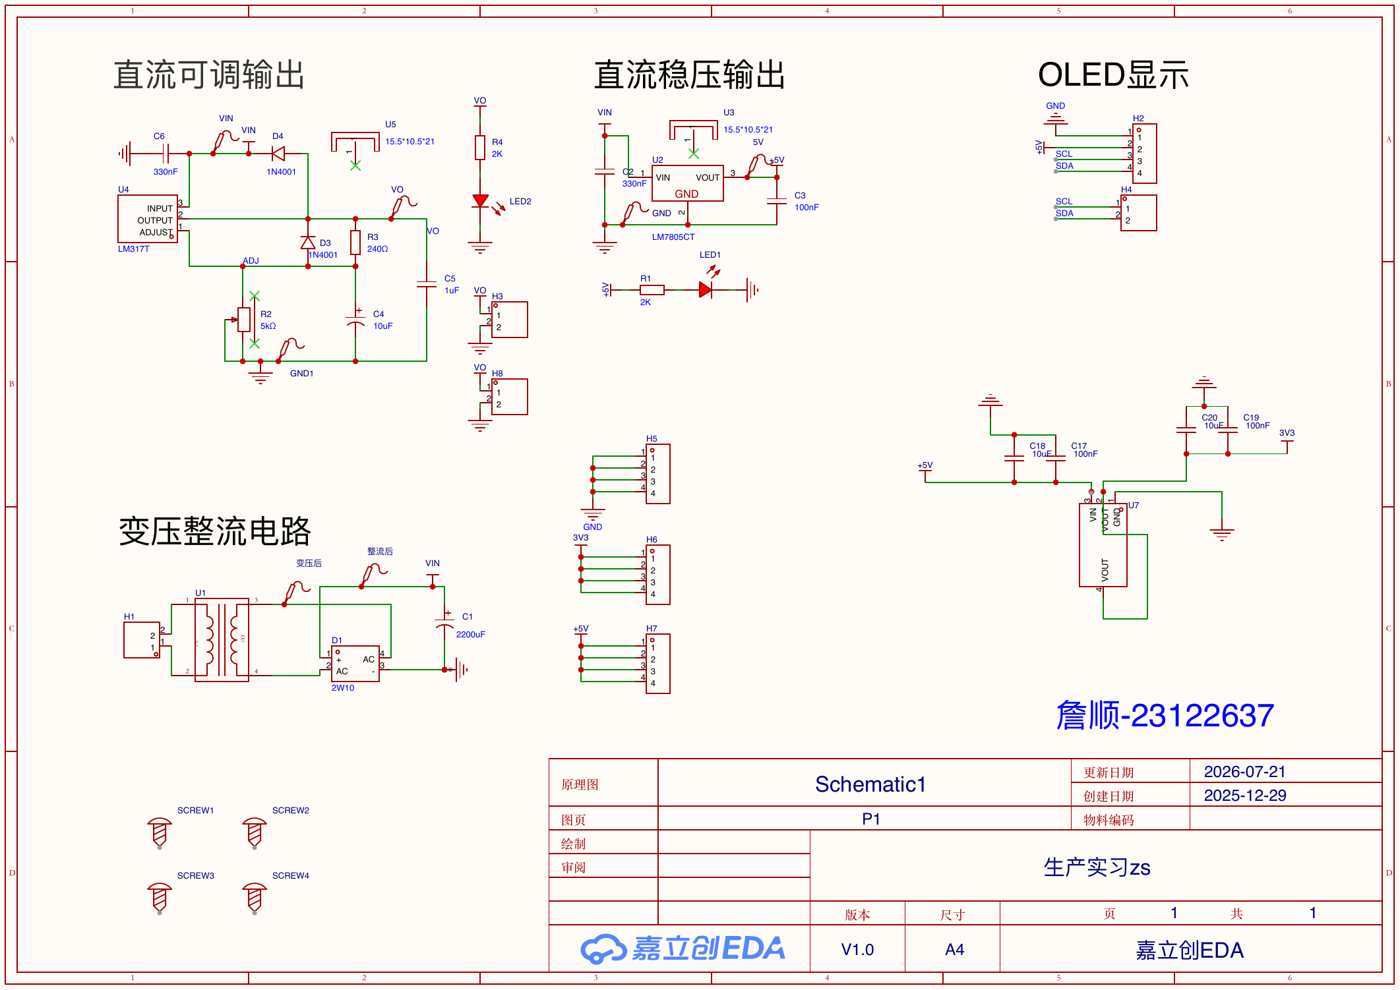
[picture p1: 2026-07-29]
tmp/pdfs/schematic-1.png

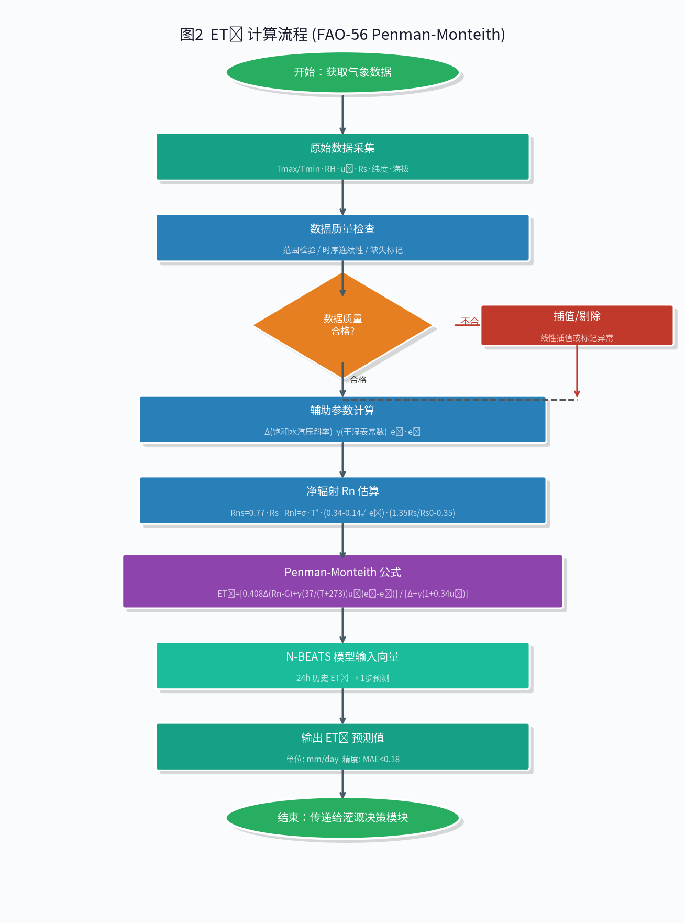
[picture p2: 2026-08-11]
fc2_et0_preview.png

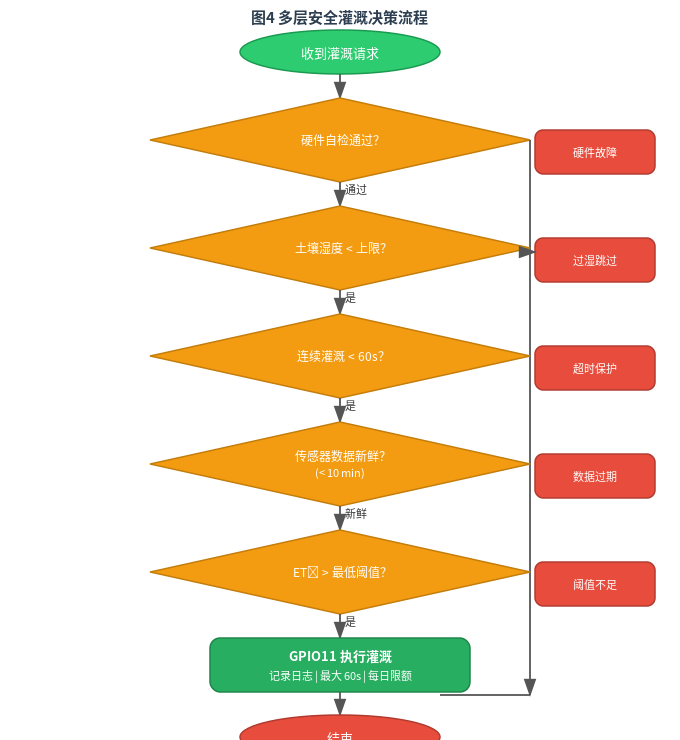
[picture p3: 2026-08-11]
fc4_safety.png

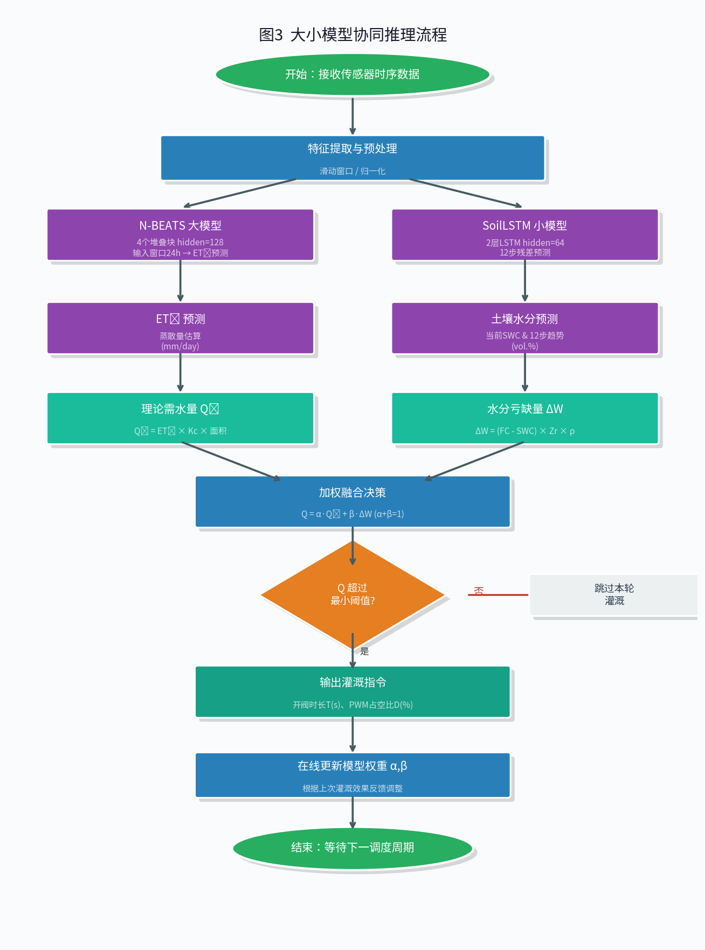
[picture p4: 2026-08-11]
fc3_dual_preview.png

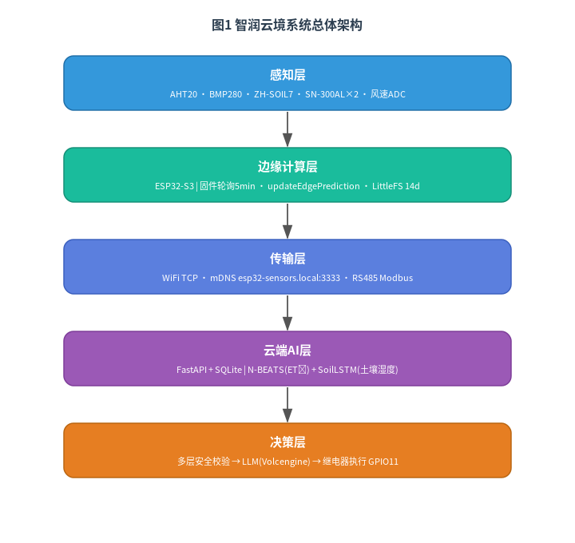
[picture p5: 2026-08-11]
fc1_preview.png

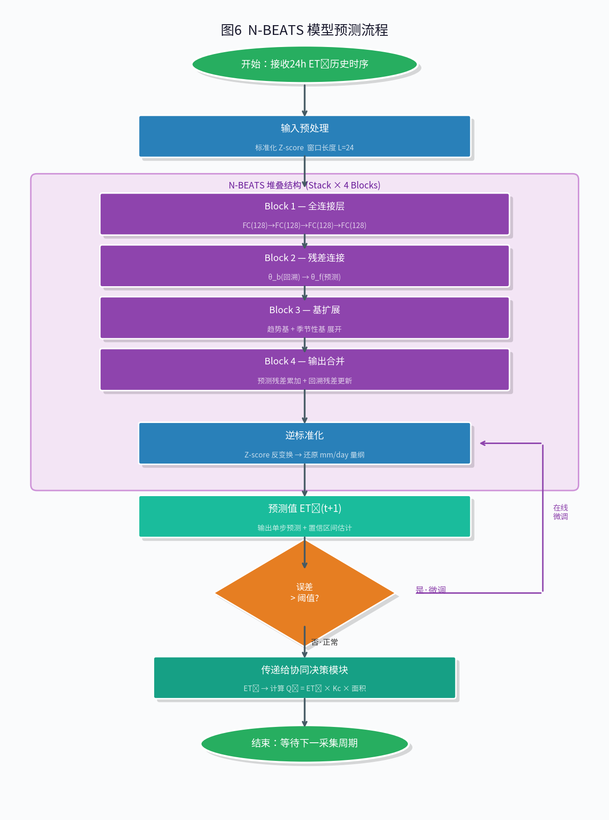
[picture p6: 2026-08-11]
fc6_nbeats_preview.png

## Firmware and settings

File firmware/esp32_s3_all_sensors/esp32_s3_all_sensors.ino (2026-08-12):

/*
  Combined sensor reader for Arduino / ESP32-S3

  Sensors:
    1. Selectable AHT20 or DHT11 air temperature/humidity sensor
    2. HW-611 / BMP280 or BME280 air pressure sensor over I2C
    3. ZH-SOIL7 soil sensor over direct TTL UART carrying Modbus-RTU frames
    4. SN-300AL-RA-N01 solar sensor 1: reflected shortwave Rs↑, RS485/Modbus
    5. SN-300AL-RA-N01 solar sensor 2: incoming shortwave Rs↓, RS485/Modbus
    6. Two analog wind speed sensors on GPIO9 and GPIO6 / ADC1

  Important:
    Soil uses direct TTL UART; the solar sensors use a separate RS485 bus.
    All devices use 4800 8N1. The soil address is 0x03; solar addresses are
    0x01 and 0x02.

  Wi-Fi provisioning and telemetry:
    On a fresh flash (or after @WIFI_RESET over USB), the ESP32 opens a temporary
    AIOT-SETUP-xxxxxx Wi-Fi network. A phone can use its local configuration
    page to store any normal 2.4 GHz WPA2 Wi-Fi/hotspot credential in ESP32
    NVS. After joining the network the ESP32 exposes its telemetry/control
    TCP endpoint as esp32-sensors.local:3333. Credentials never live in this
    source file or Git.
*/

#include <Arduino.h>
#include <Wire.h>
#include <WiFi.h>
#include <WiFiUdp.h>
#include <WebServer.h>
#include <Preferences.h>
#include <ESPmDNS.h>
#include <LittleFS.h>
#include <ArduinoJson.h>
#include <esp_heap_caps.h>
#include <time.h>
#include <sys/time.h>

#include "cloud_gateway.h"
#include "device_runtime.h"
#include "edge_model.h"

// Synthetic history exists only for a controlled, relay-locked bench test.
// A generated fixture file may be present in a working tree, so its presence
// must never turn a deployed field device into test mode by accident.
#ifndef AIOT_ENABLE_SYNTHETIC_HISTORY_FIXTURE
#define AIOT_ENABLE_SYNTHETIC_HISTORY_FIXTURE 0
#endif

// Test builds can select either the production worker task or a direct call
// from loop(). Field builds always leave both test switches disabled.
#ifndef AIOT_TEST_RUN_INFERENCE_INLINE
#define AIOT_TEST_RUN_INFERENCE_INLINE 0
#endif

#if AIOT_ENABLE_SYNTHETIC_HISTORY_FIXTURE && \
    __has_include("generated/synthetic_history_fixture.h")
#include "generated/synthetic_history_fixture.h"
#else
#define AIOT_TEST_HISTORY_FIXTURE_ENABLED 0
#endif

// -------------------- Common --------------------

static const uint32_t PC_BAUD = 115200;
// Safe unattended boot default.  With no computer connected, the ESP32
// still takes and persists one environmental record every five minutes.
// A computer can temporarily request a faster diagnostic interval, but a
// reset always returns to this storage-friendly cadence.
static const uint32_t OFFLINE_LOG_INTERVAL_MS = 5UL * 60UL * 1000UL;
static const uint32_t MISSING_SENSOR_RETRY_INTERVAL_MS = 15UL * 1000UL;
static const uint32_t DEFAULT_READ_INTERVAL_MS = OFFLINE_LOG_INTERVAL_MS;
static const uint32_t IRRIGATION_MAX_READ_INTERVAL_MS = 5000;
// The lightweight edge estimator deliberately runs much less often than
// sensor acquisition.  It is a safe, explainable fallback while the computer
// gateway or network is unavailable; it never opens the valve by itself.
static const uint32_t EDGE_PREDICTION_INTERVAL_MS = 5UL * 60UL * 1000UL;

// The USB cable used to upload this sketch can also carry telemetry to the
// local computer.  Each sample is emitted as one line beginning with
// "@TELEMETRY "; ordinary diagnostic logs use other prefixes and are ignored
// by the computer-side serial receiver.
static const bool USB_SERIAL_TELEMETRY_ENABLED = true;
static const char *USB_TELEMETRY_PREFIX = "@TELEMETRY ";
static const char *USB_COMMAND_PREFIX = "@COMMAND ";
static const char *USB_UI_COMMAND_PREFIX = "@UI_COMMAND ";
static const char *USB_UI_ACK_PREFIX = "@UI_ACK ";
static const char *USB_FORECAST_PREFIX = "@FORECAST ";
static const char *USB_IRRIGATION_STATE_PREFIX = "@IRRIGATION_STATE ";
static const char *USB_CLOUD_RESULT_PREFIX = "@CLOUD_RESULT ";
static const char *USB_ACK_PREFIX = "@ACK ";
static const char *USB_CONFIG_PREFIX = "@CONFIG ";
static const char *USB_CONFIG_ACK_PREFIX = "@CONFIG_ACK ";
static const char *USB_WIFI_RESET_COMMAND = "@WIFI_RESET";
static const char *USB_OFFLINE_LOG_STATUS_COMMAND = "@OFFLINE_LOG_STATUS";
static const char *USB_OFFLINE_LOG_DUMP_COMMAND = "@OFFLINE_LOG_DUMP";
static const char *USB_OFFLINE_LOG_ERASE_COMMAND = "@OFFLINE_LOG_ERASE CONFIRM";
static const char *USB_HISTORY_IMPORT_BEGIN_PREFIX = "@HISTORY_IMPORT_BEGIN ";
static const char *USB_HISTORY_IMPORT_RECORD_PREFIX = "@HISTORY_IMPORT_RECORD ";
static const char *USB_HISTORY_IMPORT_END_COMMAND = "@HISTORY_IMPORT_END";
static const size_t HOST_CONTROL_LINE_CAPACITY = 1024;

// -------------------- Water valve relay --------------------

// One-channel 3.3 V relay input, configured as HIGH-level active. The
// normally-closed water valve power circuit uses relay COM + NO, so LOW is
// always the safe/off state. The display experiment is disabled; GPIO11 is
// now reserved exclusively for this relay.
static const uint8_t VALVE_RELAY_PIN = 11;
static const bool VALVE_RELAY_ACTIVE_HIGH = true;
static const uint32_t MAX_WATERING_MS = 60000;
static const uint32_t HOST_HEARTBEAT_TIMEOUT_MS = 8000;

bool valveOpen = false;
uint32_t valveCloseAtMs = 0;
uint32_t lastHostHeartbeatMs = 0;
uint32_t valveOpenedAtMs = 0;
bool valveRequiresHostHeartbeat = true;
bool valveOpenedByLocalAuto = false;
bool latestSensorSnapshotValid = false;
bool tcpClientJustConnected = false;
uint32_t lastTcpTelemetryEmitMs = 0;
char activeRequestId[101] = {};
char lastRequestId[101] = {};
uint32_t readIntervalMs = DEFAULT_READ_INTERVAL_MS;
char samplingMode[32] = "OFFLINE_LOGGING";
uint32_t nextSensorReadAtMs = 0;

// -------------------- Wi-Fi provisioning and legacy TCP telemetry --------------------

// Saved credentials let the ESP32 join normal 2.4 GHz WPA2
// home/router/phone/Windows-hotspot networks without recompiling. It uses
// DHCP; never set a static IP for an arbitrary hotspot.
static const bool WIFI_PROVISIONING_ENABLED = true;
static const char *WIFI_PREFERENCES_NAMESPACE = "aiot_wifi";
static const char *WIFI_PREFERENCE_SSID_KEY = "ssid";
static const char *WIFI_PREFERENCE_PASSWORD_KEY = "password";
static const char *WIFI_SETUP_AP_PREFIX = "AIOT-SETUP-";
static const char *WIFI_SETUP_AP_PASSWORD = "12345678";
static const uint8_t WIFI_SETUP_AP_MAX_CLIENTS = 2;
// Use a fixed, broadly supported 2.4 GHz channel for the temporary portal.
// More importantly, the portal below runs as a pure AP. On this ESP32-S3,
// switching directly from a failed STA association to AP+STA can report
// success while not actually beaconing an SSID.
static const uint8_t WIFI_SETUP_AP_CHANNEL = 6;
static const IPAddress WIFI_SETUP_AP_IP(192, 168, 4, 1);
static const IPAddress WIFI_SETUP_AP_GATEWAY(192, 168, 4, 1);
static const IPAddress WIFI_SETUP_AP_SUBNET(255, 255, 255, 0);
static const uint32_t WIFI_PROVISION_CONNECT_TIMEOUT_MS = 20000;
static const uint32_t WIFI_PROVISION_RETRY_INTERVAL_MS = 30000;

// The PC connects to this local TCP endpoint over the same Wi-Fi and forwards
// each packet into FastAPI. USB remains useful for flashing/debugging, but is
// no longer required for normal dashboard telemetry.
static const bool WIFI_TELEMETRY_ENABLED = true;
static const char *MDNS_HOSTNAME = "esp32-sensors";
static const uint16_t TCP_PORT = 3333;
// UDP broadcast lets the PC receiver find a DHCP-assigned ESP32 address even
// on hotspots that do not support esp32-sensors.local / mDNS.
static const uint16_t TCP_DISCOVERY_PORT = 3334;
static const uint32_t TCP_DISCOVERY_INTERVAL_MS = 3000;
static const uint32_t WIFI_RETRY_INTERVAL_MS = 10000;
static const uint32_t WIFI_STATUS_PRINT_INTERVAL_MS = 10000;
static const uint32_t TCP_DISPLAY_REFRESH_INTERVAL_MS = 2000;

// -------------------- M-series UART display --------------------

// Set true only after the display is wired through a safe 3.3 V <-> 5 V UART
// level shifter. The screen itself needs a separate power supply.
// The previous UART screen is not used in the current hardware revision.
// Keep its pins idle until a replacement display solution is selected.
static const bool DISPLAY_ENABLED = false;
// ESP32 RX <- display TX and ESP32 TX -> display RX. GPIO11/12 do not overlap
// with the existing I2C, ADC or RS485 assignments.
static const uint8_t DISPLAY_UART_RX_PIN = 12;
static const uint8_t DISPLAY_UART_TX_PIN = 13;
// The replacement M070 VisualTFT project staged on the TF card uses 19200
// baud. Keep this in sync with the project loaded on the screen itself.
static const uint32_t DISPLAY_BAUD = 19200;
static const uint32_t DISPLAY_HANDSHAKE_INTERVAL_MS = 3000;

// -------------------- Analog wind speed --------------------

// GPIO6 is the only wind sensor enabled in the current hardware build.
// Keep the wind1 fields in telemetry as disabled for PC-side protocol
// compatibility; GPIO9 is intentionally not configured or sampled.
static const bool WIND_1_ENABLED = false;
static const bool WIND_2_ENABLED = true;
static const uint8_t WIND_1_ADC_PIN = 9;
static const uint8_t WIND_2_ADC_PIN = 6;
static const uint8_t WIND_ADC_RESOLUTION_BITS = 12;
static const float WIND_ADC_FULL_SCALE_VOLTAGE = 3.3f;
// Use 5.0 / 3.3 when a divider maps a 0~5 V sensor output to 0~3.3 V.
// Set this to 1.0f only when the sensor output is guaranteed <= 3.3 V.
static const float WIND_SENSOR_VOLTAGE_GAIN = 5.0f / 3.3f;
// Keeps the user's calibration: wind speed = 27 * sensor voltage.
static const float WIND_SPEED_PER_VOLT = 27.0f;

// -------------------- AHT20 I2C --------------------

enum AirSensorType {
  AIR_SENSOR_AHT20,
  AIR_SENSOR_DHT11,
};

// AHT20 is the active air temperature/humidity sensor.
static const AirSensorType AIR_SENSOR_TYPE = AIR_SENSOR_AHT20;

// Change these to match your wiring. They intentionally avoid the RS485 pins.
// AHT20 uses the ESP32-S3's second I2C controller on separate pins.
static const uint8_t AHT20_SDA_PIN = 5;
static const uint8_t AHT20_SCL_PIN = 8;
// This Feather board switches power for its I2C/STEMMA connector with GPIO7.
static const uint8_t I2C_POWER_PIN = 7;
static const uint32_t AHT20_I2C_BAUD = 100000;
static const uint8_t AHT20_ADDR = 0x38;

// DHT11 data pin. Use GPIO10 to keep it independent from the other sensors.
static const uint8_t DHT11_DATA_PIN = 10;

enum Dht11Error {
  DHT11_OK,
  DHT11_RESPONSE_LOW_TIMEOUT,
  DHT11_RESPONSE_HIGH_TIMEOUT,
  DHT11_FIRST_BIT_TIMEOUT,
  DHT11_DATA_BIT_TIMEOUT,
  DHT11_CHECKSUM_ERROR,
};

Dht11Error dht11LastError = DHT11_OK;

// -------------------- HW-611 / BMP280 or BME280 I2C --------------------

// BMP280 uses the Feather's default I2C pins, separate from the AHT20 bus.
static const uint8_t BMP280_SDA_PIN = 3;
static const uint8_t BMP280_SCL_PIN = 4;
static const uint8_t BMP280_ADDR_PRIMARY = 0x76;
static const uint8_t BMP280_ADDR_FALLBACK = 0x77;
static const uint8_t BMP280_CHIP_ID = 0x58;
static const uint8_t BME280_CHIP_ID = 0x60;

// -------------------- Soil TTL UART / Modbus-RTU --------------------

// ZH-SOIL7 exposes TTL TX/RX directly; do not insert an RS485 transceiver.
static const int SOIL_UART_RX_PIN = 18;        // ESP32-S3 RX <- sensor TX
static const int SOIL_UART_TX_PIN = 17;        // ESP32-S3 TX -> sensor RX
static const int SOIL_UART_DE_RE_PIN = -1;     // no direction pin on TTL UART
static const uint32_t SOIL_BAUD = 4800;
static const uint8_t SOIL_ADDR = 0x03;
static const uint16_t SOIL_START_REG = 0x0000;
static const uint16_t SOIL_REG_COUNT = 2;  // temperature and moisture only

// -------------------- Solar RS485 / Modbus-RTU --------------------

// Uses a second 3.3V auto-direction RS485 converter. GPIO7 is reserved for
// I2C power on this Feather board, so it is intentionally not used here.
static const int SOLAR_RS485_RX_PIN = 16;      // ESP32-S3 RX <- converter RO
static const int SOLAR_RS485_TX_PIN = 15;      // ESP32-S3 TX -> converter DI
static const int SOLAR_RS485_DE_RE_PIN = -1;   // -1 for auto-direction module
static const uint32_t SOLAR_BAUD = 4800;

static const uint8_t SOLAR_1_ADDR = 0x01;
static const uint8_t SOLAR_2_ADDR = 0x02;
static const uint16_t SOLAR_RADIATION_REG = 0x0000;

static const uint32_t MODBUS_RESPONSE_TIMEOUT_MS = 800;
static const uint32_t MODBUS_GAP_MS = 300;

HardwareSerial SoilSerial(1);
HardwareSerial SolarSerial(2);
// UART0 is used for the optional M-series screen. Keep the USB serial monitor
// on native USB CDC when DISPLAY_ENABLED is true; a USB-to-UART monitor on
// UART0 will otherwise lose application logs and share bytes with the screen.
HardwareSerial DisplaySerial(0);
TwoWire AhtWire(1);
WiFiServer TcpServer(TCP_PORT);
WiFiClient TcpClient;
WiFiUDP TcpDiscoveryUdp;
WebServer WifiSetupServer(80);
Preferences WifiPreferences;

bool wifiReady = false;
bool wifiMdnsReady = false;
uint32_t lastWifiRetryMs = 0;
uint32_t lastTcpDiscoveryMs = 0;
bool wifiProvisioningInitialized = false;
bool wifiSetupPortalActive = false;
bool wifiSetupRoutesRegistered = false;
bool wifiProvisioningConnecting = false;
bool wifiProvisioningConnectPending = false;
uint32_t wifiProvisioningConnectStartedMs = 0;
uint32_t wifiProvisioningConnectAtMs = 0;
uint32_t wifiProvisioningNextRetryMs = 0;
char provisionedWifiSsid[33] = {};
char provisionedWifiPassword[65] = {};
char wifiSetupApSsid[32] = {};
char wifiSetupApPassword[20] = {};

// Declared here because the USB control parser is defined before the Wi-Fi
// provisioning implementation below.
void resetWifiProvisioningFromUsb();
bool startWifi();

struct DisplayForecast {
  bool received;
  char status[32];
  uint16_t availableSamples;
  uint16_t requiredSamples;
  float nextHourEt0Mm;
  float soilMoistureInOneHour;
};

DisplayForecast displayForecast = {};
bool displayInitialized = false;
uint32_t displayRxBytes = 0;
uint32_t displayHandshakeReplies = 0;
uint32_t lastDisplayHandshakeMs = 0;
bool displayHandshakeConfirmed = false;

struct AirData {
  float temperatureC;
  float humidityPercent;
};

struct SoilData {
  float temperatureC;
  float moisturePercent;
};

struct Bmp280Calibration {
  uint16_t digT1;
  int16_t digT2;
  int16_t digT3;
  uint16_t digP1;
  int16_t digP2;
  int16_t digP3;
  int16_t digP4;
  int16_t digP5;
  int16_t digP6;
  int16_t digP7;
  int16_t digP8;
  int16_t digP9;
};

Bmp280Calibration bmp280Calibration = {};
uint8_t bmp280Address = 0;
bool bmp280Ready = false;

// One complete sensor acquisition. The ok flags show whether the matching
// value set was read successfully during this sampling cycle.
struct SensorSnapshot {
  uint32_t uptimeMs;

  bool wind1Ok;
  float wind1Voltage;
  float wind1SpeedMs;

  bool wind2Ok;
  float wind2Voltage;
  float wind2SpeedMs;

  // Air pressure in hPa. A value of 0 means the BMP280/BME280 read failed.
  uint16_t AirPressure;

  bool airOk;
  AirData air;

  bool soilOk;
  SoilData soil;

  bool solar1Ok;
  uint16_t solarRadiation1Wm2;

  bool solar2Ok;
  uint16_t solarRadiation2Wm2;
};

// Arduino's sketch preprocessor creates function declarations before this
// file's later helper types.  Forward-declaring this one keeps those generated
// declarations valid; its full layout remains next to the edge estimator.
struct EdgePrediction;
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
void loop() {
  serviceUsbControl();
  serviceWifi();
  serviceWifiProvisioning();
  serviceDeviceRuntime();

  // A dashboard may connect between two five-minute sensor acquisitions.
  // Replay the latest complete sample immediately instead of making it wait
  // for the next acquisition slot.
  if (tcpClientJustConnected && lastTelemetrySnapshotAvailable) {
    sendTelemetry(lastTelemetrySnapshot, lastTelemetryEdgePrediction);
    lastTcpTelemetryEmitMs = millis();
    tcpClientJustConnected = false;
  }

  // Refresh the computer display from the cached sample. This does not read
  // sensors or run either prediction model; those remain on their own cadence.
  if (lastTelemetrySnapshotAvailable && TcpClient && TcpClient.connected() &&
      millis() - lastTcpTelemetryEmitMs >= TCP_DISPLAY_REFRESH_INTERVAL_MS) {
    sendTelemetry(lastTelemetrySnapshot, lastTelemetryEdgePrediction);
    lastTcpTelemetryEmitMs = millis();
  }

  if (static_cast<int32_t>(millis() - nextSensorReadAtMs) < 0) {
    delay(2);
    return;
  }

  Serial.println("========== Sensor Data ==========");

  SensorSnapshot snapshot = {};
  snapshot.uptimeMs = millis();

  if (WIND_1_ENABLED) {
    snapshot.wind1Ok =
        readWindSpeed(WIND_1_ADC_PIN, snapshot.wind1Voltage, snapshot.wind1SpeedMs);
  }

  if (WIND_2_ENABLED) {
    snapshot.wind2Ok =
        readWindSpeed(WIND_2_ADC_PIN, snapshot.wind2Voltage, snapshot.wind2SpeedMs);
  }
  if (snapshot.wind2Ok) {
    Serial.printf("Wind (GPIO%d) voltage: %.3f V\n", WIND_2_ADC_PIN,
                  snapshot.wind2Voltage);
    Serial.printf("Wind (GPIO%d) speed: %.2f m/s\n", WIND_2_ADC_PIN,
                  snapshot.wind2SpeedMs);
  } else {
    Serial.printf("Wind speed sensor on GPIO%d read failed.\n", WIND_2_ADC_PIN);
  }

  if (readBmp280Pressure(snapshot.AirPressure)) {
    Serial.printf("Air pressure: %u hPa\n", snapshot.AirPressure);
  } else {
    Serial.println("BMP280/BME280 pressure read failed.");
  }

  snapshot.airOk = readConfiguredAirSensor(snapshot.air);
  if (snapshot.airOk) {
    Serial.printf("Air temperature: %.2f C\n", snapshot.air.temperatureC);
    Serial.printf("Air humidity: %.2f %%RH\n", snapshot.air.humidityPercent);
  } else {
    if (AIR_SENSOR_TYPE == AIR_SENSOR_DHT11) {
      Serial.print("DHT11 read failed: ");
      Serial.println(dht11ErrorText());
    } else {
      Serial.println("AHT20 read failed.");
    }
  }
  serviceWifi();
  serviceWifiProvisioning();

  snapshot.soilOk = readSoilSensor(snapshot.soil);
  if (snapshot.soilOk) {
    Serial.printf("Soil temperature: %.1f C\n", snapshot.soil.temperatureC);
    Serial.printf("Soil moisture: %.1f %%\n", snapshot.soil.moisturePercent);
  } else {
    Serial.println("Soil sensor read failed.");
  }
  serviceWifi();
  serviceWifiProvisioning();

  delay(MODBUS_GAP_MS);

  snapshot.solar1Ok = readSolarRadiation(SOLAR_1_ADDR, snapshot.solarRadiation1Wm2);
  if (snapshot.solar1Ok) {
    Serial.printf("Solar reflected (sensor 1): %u W/m2\n", snapshot.solarRadiation1Wm2);
  } else {
    Serial.println("Solar reflected sensor 1 read failed.");
  }
  serviceWifi();
  serviceWifiProvisioning();

  delay(MODBUS_GAP_MS);

  snapshot.solar2Ok = readSolarRadiation(SOLAR_2_ADDR, snapshot.solarRadiation2Wm2);
  if (snapshot.solar2Ok) {
    Serial.printf("Solar incoming (sensor 2): %u W/m2\n", snapshot.solarRadiation2Wm2);
  } else {
    Serial.println("Solar incoming sensor 2 read failed.");
  }

  if (snapshot.solar2Ok) {
    Serial.printf("Solar net shortwave: %.0f W/m2 (%s)\n", netShortwaveRadiation(snapshot),
                  snapshot.solar1Ok ? "measured reflection" : "default albedo fallback");
  }

  latestSensorSnapshotValid =
      (snapshot.wind1Ok || snapshot.wind2Ok) && snapshot.AirPressure > 0 &&
      snapshot.airOk && snapshot.soilOk &&
      snapshot.solar2Ok;
  const EdgePrediction edgePrediction = updateEdgePrediction(snapshot);
  if (edgePrediction.valid) {
    Serial.printf("ESP32 edge prediction: soil in 30 min %.1f %% | drying %.3f %%/h | %s (%s)\n",
                  edgePrediction.predictedSoilMoisture30mPercent,
                  edgePrediction.dryingRatePercentPerHour,
                  edgePrediction.riskLevel, edgePrediction.reason);
  } else {
    Serial.println("ESP32 edge prediction: unavailable (sensor_invalid).");
  }
  serviceUsbControl();
  updateDisplay(snapshot);
  lastTelemetrySnapshot = snapshot;
  lastTelemetryEdgePrediction = edgePrediction;
  lastTelemetrySnapshotAvailable = true;
  sendTelemetry(snapshot, edgePrediction);
  lastTcpTelemetryEmitMs = millis();
  tcpClientJustConnected = false;
  processDeviceRuntimeSample(snapshot);

  // A failed sample is still reported to USB/Wi-Fi for diagnosis, but never
  // enters offline history.  Retry after 15 seconds and keep retrying until a
  // fully populated row exists.  A successful row resumes the configured
  // cadence, which is five minutes after boot without a computer.
  const bool completeForOfflineLog = offlineSnapshotIsComplete(snapshot);
  const bool dueForFlashWrite =
      lastOfflineLogSavedMs == 0 ||
      snapshot.uptimeMs - lastOfflineLogSavedMs >= OFFLINE_LOG_INTERVAL_MS;
  if (!completeForOfflineLog) {
    Serial.printf("[OFFLINE LOG] Missing sensor; retrying in %lu seconds without saving this row.\n",
                  static_cast<unsigned long>(MISSING_SENSOR_RETRY_INTERVAL_MS / 1000));
    nextSensorReadAtMs = millis() + MISSING_SENSOR_RETRY_INTERVAL_MS;
  } else {
    if (dueForFlashWrite && !deviceInferenceBusy && !deviceInferenceRequested) {
      if (appendOfflineLog(snapshot)) {
        Serial.printf("[OFFLINE LOG] Saved complete sample (%u current, %u previous).\n",
                      static_cast<unsigned>(offlineLogRecordCount(OFFLINE_LOG_CURRENT_PATH)),
                      static_cast<unsigned>(offlineLogRecordCount(OFFLINE_LOG_PREVIOUS_PATH)));
      } else {
        Serial.println("[OFFLINE LOG] Complete sample was not saved; retrying in 15 seconds.");
        nextSensorReadAtMs = millis() + MISSING_SENSOR_RETRY_INTERVAL_MS;
        Serial.println("=================================");
        return;
      }
    }
    nextSensorReadAtMs = millis() + readIntervalMs;
  }
  Serial.println("=================================");
}

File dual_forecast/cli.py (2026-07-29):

from __future__ import annotations

import argparse
import json
import getpass
import os
import tempfile
from dataclasses import asdict, replace
from pathlib import Path

from .config import SETTINGS
from .esp32_receiver import add_receiver_parser
from .offline_log import add_offline_log_parser


def _settings(args):
    return replace(SETTINGS, artifact_dir=Path(args.artifacts), database_path=Path(args.database))


def preprocess(args):
    from .history import add_proxy_soil_moisture, load_hongqiao_zip

    settings = _settings(args)
    source = load_hongqiao_zip(args.zip, settings)
    warnings = source.attrs.get("quality_warnings", [])
    frame = add_proxy_soil_moisture(source, settings)
    Path(args.output).parent.mkdir(parents=True, exist_ok=True)
    frame.to_csv(args.output)
    print(json.dumps({"rows": len(frame), "start": str(frame.index.min()), "end": str(frame.index.max()), "output": args.output, "qualityWarnings": warnings}, ensure_ascii=False))


def train_all(args):
    from .history import add_proxy_soil_moisture, load_hongqiao_zip, split_chronologically
    from .training import prepare_soil_frame, train_lstm, train_nbeats, write_metadata

    settings = _settings(args)
    hourly = add_proxy_soil_moisture(load_hongqiao_zip(args.zip, settings), settings)
    train, validation, test = split_chronologically(hourly)
    et0_metrics = train_nbeats(train, validation, test, settings, epochs=args.epochs)
    soil_parts = [prepare_soil_frame(part, interpolate_to_5min=True) for part in (train, validation, test)]
    soil_metrics = train_lstm(*soil_parts, settings, data_type="proxy", epochs=args.epochs)
    write_metadata(settings, et0=asdict(et0_metrics), soil=asdict(soil_metrics))
    print(json.dumps({"et0": asdict(et0_metrics), "soil": asdict(soil_metrics)}, indent=2))


def train_et0_only(args):
    from .history import add_proxy_soil_moisture, load_hongqiao_zip, split_chronologically
    from .training import train_nbeats, write_metadata

    settings = _settings(args)
    hourly = add_proxy_soil_moisture(load_hongqiao_zip(args.zip, settings), settings)
    metrics = train_nbeats(*split_chronologically(hourly), settings, epochs=args.epochs)
    write_metadata(settings, et0=asdict(metrics))
    print(json.dumps(asdict(metrics), indent=2))


def train_soil_proxy(args):
    from .history import add_proxy_soil_moisture, load_hongqiao_zip, split_chronologically
    from .training import prepare_soil_frame, train_lstm, write_metadata

    settings = _settings(args)
    hourly = add_proxy_soil_moisture(load_hongqiao_zip(args.zip, settings), settings)
    parts = [prepare_soil_frame(part, interpolate_to_5min=True) for part in split_chronologically(hourly)]
    metrics = train_lstm(*parts, settings, data_type="proxy", epochs=args.epochs)
    write_metadata(settings, soil=asdict(metrics))
    print(json.dumps(asdict(metrics), indent=2))


def retrain_observed(args):
    from .history import split_chronologically
    from .storage import Store
    from .training import prepare_soil_frame, train_lstm

    settings = _settings(args)
    store = Store(settings.database_path)
    days = store.observed_span_days()
    if days < settings.observed_retrain_days:
        raise SystemExit(f"need {settings.observed_retrain_days} observed days; only {days:.2f} available")
    frame = store.recent_frame(limit=1_000_000)
    frame = frame.rename(columns={})
    prepared = prepare_soil_frame(frame, interpolate_to_5min=False)
    train, validation, test = split_chronologically(prepared)
    metrics = train_lstm(train, validation, test, settings, data_type="observed", epochs=args.epochs)
    print(json.dumps(asdict(metrics), indent=2))


def export_latest(args):
    import pandas as pd

    from .storage import Store

    response = Store(args.database).latest_forecast()
    if response is None:
        raise SystemExit("no forecast is available")
    pd.DataFrame([point.model_dump() for point in response.forecast]).to_csv(args.output, index=False)
    print(args.output)


def _write_cloud_env(api_key: str, env_path: Path | None = None) -> Path:
    """Update cloud keys without deleting unrelated local deployment settings."""
    if not api_key.strip():
        raise SystemExit("VEI API Key cannot be empty")
    if "\n" in api_key or "\r" in api_key:
        raise SystemExit("VEI API Key must be a single line")
    env_path = env_path or Path(__file__).resolve().parents[1] / ".env"
    updates = {
        "AIOT_LLM_ENABLED": "1",
        "VEI_API_KEY": api_key.strip(),
        "VEI_BASE_URL": "https://ai-gateway.vei.volces.com/v1",
        "VEI_MODEL": "doubao-1.5-thinking-pro",
        "VEI_TIMEOUT_SECONDS": "45",
        "AIOT_LLM_INTERVAL_MINUTES": "15",
        "AIOT_DEMO_AUTO_EXECUTE": "0",
    }
    existing = env_path.read_text(encoding="utf-8").splitlines() if env_path.is_file() else [
        "# Local only. This file is ignored by Git; do not share it."
    ]
    output: list[str] = []
    written: set[str] = set()
    for line in existing:
        stripped = line.strip()
        key = stripped.split("=", 1)[0].strip() if "=" in stripped and not stripped.startswith("#") else None
        if key in updates:
            if key not in written:
                output.append(f"{key}={updates[key]}")
                written.add(key)
            continue
        output.append(line)
    if output and output[-1]:
        output.append("")
    for key, value in updates.items():
        if key not in written:
            output.append(f"{key}={value}")
    output.append("")

    env_path.parent.mkdir(parents=True, exist_ok=True)
    fd, temporary_name = tempfile.mkstemp(prefix=".env.", suffix=".tmp", dir=env_path.parent)
    try:
        with os.fdopen(fd, "w", encoding="utf-8") as temporary:
            temporary.write("\n".join(output))
        os.replace(temporary_name, env_path)
    finally:
        if os.path.exists(temporary_name):
            os.unlink(temporary_name)
    return env_path


def configure_cloud(args):
    api_key = getpass.getpass("Paste Volcengine VEI API Key (input hidden): ").strip()
    path = _write_cloud_env(api_key)
    print(f"Saved local cloud configuration: {path}")
    print("Cloud is enabled; automatic valve execution remains disabled.")
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

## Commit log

2026-07-12 feat: 接入 ESP32 传感器 TCP 数据并驱动预测模型
    新增 ESP32 TCP 数据接收桥接程序，将采集 JSON 转换为 SensorSnapshot 并提交至预测服务。
    支持风速、空气温湿度、气压、土壤温湿度及两路太阳辐射数据。
    默认按五分钟间隔写入预测历史，气压传感器未接入时使用 1013 hPa 作为临时值。
    补充字段映射测试和使用说明。
2026-07-14 chore: 完善项目环境配置与一键启动流程
2026-07-14 fix: win修缮
2026-07-15 fix: esp32
    [partitions.csv]
2026-07-17 新增电脑热点联网与实时监控页面
2026-07-17 分离实时监控与预测采样通道
2026-07-17 跳过不完整采集包并保留实时显示
2026-07-17 补充 Windows 实时监控运行说明
2026-07-17 新增全屏一键启动与实时状态提示
2026-07-17 修复一键启动的浏览器兼容性
2026-07-17 补充一键启动的实时日志与连通性检测
2026-07-17 修正 Windows 热点网段配置
2026-07-17 改用 USB 串口传输采集数据
2026-07-17 修复本机代理阻断串口数据提交
2026-07-17 完善跨平台实时监控启动脚本
2026-07-17 启动时校验实时数据链路
2026-07-20 实现云端大模型增强与安全灌溉闭环
2026-07-20 完善边缘事件与移动巡检能力
2026-07-21 增加 ESP32 手机 Wi-Fi 配网
2026-07-21 统一 Wi-Fi 配网热点密码
2026-07-21 完善 Wi-Fi 自动接收与跨平台一键启动
2026-07-21 忽略本地编译产物与临时固件
    [partitions.csv]
2026-07-23 完善云端大模型配置与自动灌溉安全闭环
2026-07-24 feat:加入了fast test模式
2026-07-24 feat: 区分太阳入射反射并使用净短波计算ET0
2026-07-24 feat:修改了et0
2026-07-24 feat:优化了ui
2026-07-24 feat:更改了决策逻辑
2026-07-24 feat：优化了给豆包的提示词
2026-07-24 feat:水阀控制和界面好了
2026-07-24 feat:加入了全自动模式
2026-07-24 feat：ui加入了tcp数据流
2026-07-24 feat;困死了，不想写提交，希望起来rjh把视频拍完
2026-07-25 feat: 支持ESP32离线完整数据采集
2026-07-29 feat:离线存储
    [Drill_NPTH_Through.DRL, Drill_PTH_Through.DRL, Drill_PTH_Through_Via.DRL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]
2026-08-11 feat: esp32本地模型
    [esp32-offline-log.csv]
2026-08-12 fix：ESP32-S3 推理模型已成功部署并验证。
2026-08-12 fix：ESP32-S3 ai模型部署
2026-08-12 fix：导入历史记录
